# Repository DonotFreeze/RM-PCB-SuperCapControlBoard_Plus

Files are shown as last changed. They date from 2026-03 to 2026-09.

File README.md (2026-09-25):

# 超级电容控制板 Plus

> 桂林理工大学 · 群星战队 · RoboMaster 2025 赛季开源工程

基于 **STM32G431CB** 的单半桥双向同步 Buck-Boost 超级电容控制板，用于RobaMaster机甲大师赛2025赛季超级对抗赛。相较 2024 赛季开源的 Lite 版本，Plus 版本围绕**远端电压补偿**、**下管电流采样**与**硬件保护**三个方面进行了重点改进，并重新设计了充放电环路逻辑。

> **完整的硬件设计说明** → [RM2025 超级电容控制板 Plus「硬件篇」 · DonotFreeze 的知识库](https://donotfreeze.github.io/robomaster/supercap-controller-plus-hardware/)

<p align="center">
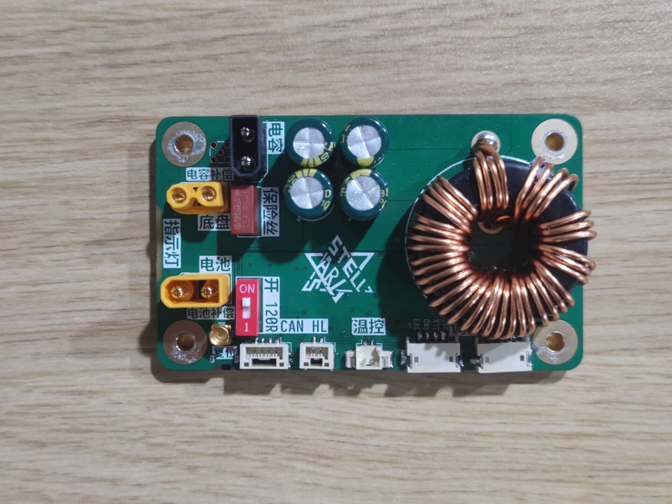
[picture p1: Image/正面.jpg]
超级电容控制板 Plus 正面
  
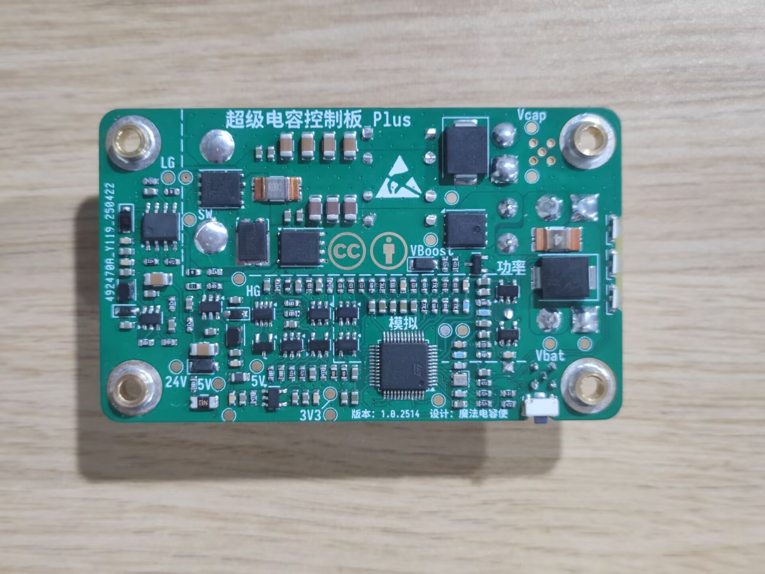
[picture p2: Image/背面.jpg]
超级电容控制板 Plus 背面
  
</p>

## 主要特性

- **远端电压补偿**：通过 MMCX-KWE 接口 + 差分放大器，把电压采样点从板端移到电源管理模块 Chassis 端口，抵消导线线损带来的功率采样误差（24V、0–10A 范围内与裁判系统误差 ≤ ±1W，未补偿时误差约 -5W）。
- **下管续流电流采样**：采用差分放大器进行下管低边采样，搭配 2mΩ 检流电阻，量程 -20A ~ +40A（充电为负、放电为正），有效电流分辨率约 0.1A，取代 Lite 版本的 INA181。节省成本的同时提高可靠性，但是在一定程度上损失了精度。
- **硬件保护**：母线电源端口带有 TVS、并在半桥拓扑支路上有一个5A慢断保险丝，可在一定程度上保证控制板烧毁而不影响母线。辅助电源有自恢复保险丝 + 限流电阻 + 小功率 TVS 的浪涌保护。功率相关引脚 ESD 防护及其熔断检测、PMOS 与 PWM 的硬件时序延迟电路。
- **单电感同步半桥**：PMOS 防倒灌 + 半桥 Buck/Boost，配合硬件/软件时序控制保证 PMOS 先于 PWM 导通、后于 PWM 关断。

## 硬件规格

| 项目 | 参数 |
| --- | --- |
| 主控 | STM32G431CBT6 |
| 拓扑 | 同步 Buck-Boost 半桥（降压充电 / 升压放电） |
| 半桥 MOS | IRFH7440 × 2 |
| 防倒灌 PMOS | AGM60P100A |
| 栅极驱动 | LM5109 |
| 母线电流采样 | 4mΩ + INA139/INA193 兼容 |
| 电流采样 | 2mΩ 分流电阻 + 差分放大器 |
| 温度采样 | 半桥温度NTC + 外接电容组NTC |
| 通信 | CAN |
| 辅助电源 | MP2456 × 2 + RT9193（3.3V） |
| 尺寸 | 45 × 75 × 20 mm（面积与孔位与电容组一致，可直接堆叠） |

## 工程结构

```text
├─ SuperCapControlBoard_Plus.kicad_pro / .kicad_sch / .kicad_pcb   # KiCad 8.0 工程（原理图 + PCB）
├─ POWER.kicad_sch                     # 功率级原理图
├─ BOM/
│  ├─ SuperCapPowerBoard_Plus.csv      # 已附立创商城编号的 BOM
│  └─ ibom.html                        # 交互式 BOM（点击可定位元件）
├─ GERBER/                             # Gerber 生产文件（Plus / PULS 版本）
├─ 模型文件/                           # 3D STEP 模型
├─ Docs/                               # 参考资料（TI《高速低侧电流检测参考设计》）
├─ Image/                              # 文档配图
└─ CHANGELOG.md                        # 版本更新日志
```

## 固件代码

本仓库为**纯硬件工程**，不包含固件源码。固件由以下两个独立仓库提供，与本硬件配套使用：

| 仓库 | 说明 |
| --- | --- |
| [**RM-CODE-SuperCapControlBoard_Plus**](https://github.com/DonotFreeze/RM-CODE-SuperCapControlBoard_Plus) | RM2025 赛季超级电容控制板 Plus 的 **CubeMX 代码初始化工程**，提供 STM32 底层外设的 CubeMX 配置 |
| [**RM-SuperCapCtrlLib**](https://github.com/DonotFreeze/RM-SuperCapCtrlLib) | 参加 RoboMaster 机甲大师赛期间开发的 **C 语言库**，可同时用于超级电容控制板 **Lite 和 Plus**，负责充放电环路控制与对外接口 |

## 物料与打样

- BOM 已附立创商城编号，可直接一键下单；建议一次性采购 10 套用量以获得较优价格（约 90 元/套，2025 年 5 月）。
- 全部芯片若在优信电子采购，成本可再降低约 20 元/套（其中 **MP2456 强烈建议到优信购买**）。
- 磁环电感立创商城无货、未列入 BOM，需自行采购 **106-125 磁环**（四线 1.0mm 并绕 11 匝，初始感量约 22µH），磁芯型号务必一致以保证感量与饱和电流。

---

## 参考文献

- 高速低侧电流检测参考设计 (Rev. C) —— 见 `Docs/《高速低侧电流检测参考设计-TI》.pdf`
- 电源远端电压补偿 / 远端补偿电源电路 —— CSDN 博客

## 特别鸣谢

感谢以下战队在 Lite 版本中的使用反馈（排名不分先后，想到谁就写谁）：

- 江南大学霞客湾校区 - SHARK 战队
- 北京理工大学珠海学院 - 毅恒战队
- 厦门大学嘉庚学院 - TCR 战队
- 宁波诺丁汉大学 - AIM 战队
- 浙江理工大学 - 钱塘蛟战队

## 许可证

本作品采用 [CC-BY-4.0](https://creativecommons.org/licenses/by/4.0/legalcode) 许可协议进行授权，欢迎转载，但请务必保留作者署名。

## 相关链接

- [RM2025 超级电容控制板 Plus「硬件篇」](https://donotfreeze.github.io/robomaster/supercap-controller-plus-hardware/)（本工程的设计说明）
- [固件代码 · RM-CODE-SuperCapControlBoard_Plus](https://github.com/DonotFreeze/RM-CODE-SuperCapControlBoard_Plus)（CubeMX 代码初始化工程）
- [固件代码 · RM-SuperCapCtrlLib](https://github.com/DonotFreeze/RM-SuperCapCtrlLib)（Lite / Plus 通用的 C 语言库）
- [RM2024 超级电容控制板 Lite「硬件篇」](https://donotfreeze.github.io/robomaster/supercap-controller-lite-hardware/)
- [RM2025 超级电容模组 Plus「使用手册」](https://donotfreeze.github.io/robomaster/supercap-module-plus-user-manual/)
- [RM24-25 超级电容控制板 Lite & Plus「CubeMX 篇」](https://donotfreeze.github.io/robomaster/supercap-controller-cubemx/)
- [RM24-25 超级电容模组 Lite & Plus「答疑篇」](https://donotfreeze.github.io/robomaster/supercap-module-faq/)
- [DonotFreeze 的知识库](https://donotfreeze.github.io/)

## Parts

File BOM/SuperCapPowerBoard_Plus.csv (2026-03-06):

Reference | Value | Footprint | Qty | 型号 | 立创编号
C1,C3,C8,C9,C10,C11,C13,C16,C18,C19,C20,C21,C27,C29,C30,C31,C32,C33,C34,C38,C39,C41,C42,C43,C47,C49,C53,C57,C59,C60 | 100nF | 0_Capacitor_SMD:C_0603_1608Metric | 30 | 0603B104K500NT | C30926
C2,C12,C17,C22 | 4.7uF | 0_Capacitor_SMD:C_0603_1608Metric | 4 | 0603X475M100NT | C2857987
C4,C5,C6 | 47nF | 0_Capacitor_SMD:C_0603_1608Metric | 3 | 0603B473K500NT | C285123
C7 | 1nF | 0_Capacitor_SMD:C_0603_1608Metric | 1 | 0603B102K500NT | C44369
C14,C15 | 12pF | 0_Capacitor_SMD:C_0603_1608Metric | 2 | 0603CG120J500NT | C1642
C23,C44,C45,C46,C56,C58 | 10uF | 0_Capacitor_SMD:C_0603_1608Metric | 6 | 0603X106K160NT | C70225
C24,C25,C35,C36,C37,C51,C52,C54,C55 | 10uF | Capacitor_SMD:C_1206_3216Metric | 9 | 1206X106K500NT | C116702
C26,C28,C48,C50 | 100uF | Capacitor_THT:CP_Radial_D8.0mm_P3.50mm | 4 | CD2881071HM0812VFL | C7493835
C40 | 22nF | 0_Capacitor_SMD:C_0603_1608Metric | 1 | 0603B223K500NT | C77571
D1 | XL-3210UGC | 0_LED_SMD:LED_1204_3210 | 1 | XL-3210UGC | C965877
D2 | XL-3210UBC | 0_LED_SMD:LED_1204_3210 | 1 | XL-3210UBC | C965879
D3 | PESD24VL2B | Package_TO_SOT_SMD:SOT-23 | 1 | PESD24VL2B | C28310452
D4 | XL-3210SURC | 0_LED_SMD:LED_1204_3210 | 1 | XL-3210SURC | C965874
D5 | SMF26A | Diode_SMD:D_SMF | 1 | SMF26A | C41376090
D6 | SMF12A | Diode_SMD:D_SMF | 1 | SMF12A | C19077506
D7,D8 | 1N5819WS | Diode_SMD:D_SOD-323_HandSoldering | 2 | 1N5819WS | C2927280
D9 | SB1045L | Package_TO_SOT_SMD:TO-277A | 1 | SB1045L | C5277965
D10,D11 | SMCJ28A | Diode_SMD:D_SMC | 2 | SMCJ28A | C42371538
D12 | 1N5819W | Diode_SMD:D_SOD-123F | 1 | 1N5819W | C963381
F1 | 1206L010/60NR | Fuse:Fuse_1206_3216Metric | 1 | 1206L010/60NR | C7542927
F2 | 2010T5A250V | 0_Fuse:Fuse_Littelfuse_395Series | 1 | 2010T5A250V | C354906
J1,J2 | MMCX-KWE | 0_Connector_RF:MMCX_KWE_TH_Horizontal | 2 | MMCX-KWE | C5137199
J3 | MX1.25-2PIN | Connector_Molex:Molex_PicoBlade_53398-0271_1x02-1MP_P1.25mm_Vertical | 1 | ZX-MX1.25-2PLT | C7430473
J4 | GH1.25-2PIN | Connector_JST:JST_GH_BM02B-GHS-TBT_1x02-1MP_P1.25mm_Vertical | 1 | ZX-BX-GH1.25-LT2 | C7429506
J5 | GH1.25-4PIN | Connector_JST:JST_GH_BM04B-GHS-TBT_1x04-1MP_P1.25mm_Vertical | 1 | ZX-BX-GH1.25-LT4 | C7429508
J6,J7 | ZH1.5_4PIN | 0_Connector_JST:JST_ZH_1x04_-1MP_P1.5mm_MIX_MX_1x04-1MP_P1.25_Horizontal | 2 | ZX-ZH1.5-4PWT | C19272407
L1 | 330R@100Mhz | Inductor_SMD:L_0805_2012Metric | 1 | BLM21PG331SN1D | C74764
L2,L3 | APSWPA252012S220MTF | Inductor_SMD:L_Sunlord_SWPA252012S | 2 | APSWPA252012S220MTF | C42380099
Q1 | DTC143ZCA | Package_TO_SOT_SMD:SOT-23 | 1 | DTC143ZCA | C194251
Q2 | AGM60P100A | Package_DFN_QFN:AO_DFN-8-1EP_5.55x5.2mm_P1.27mm_EP4.12x4.6mm | 1 | AGM60P100A | C5373096
Q3,Q4 | IRFH7440 | Package_TO_SOT_SMD:TDSON-8-1 | 2 | IRFH7440 | C67862
R1,R2,R3,R4,R5,R6,R30,R35 | 10K | 0_Resustor_SMD:R_0603_1608Metric | 8 | RS-03K1002FT | C115324
R7,R8,R9,R10 | 1M | 0_Resustor_SMD:R_0603_1608Metric | 4 | RS-03K1004FT | C136593
R11,R17 | 200K | 0_Resustor_SMD:R_0603_1608Metric | 2 | RS-03K2003FT | C95331
R12 | 20K | 0_Resustor_SMD:R_0603_1608Metric | 1 | RS-03K2002FT | C136589
R13,R14,R15,R16 | 62K | 0_Resustor_SMD:R_0603_1608Metric | 4 | RS-03K6202FT | C95332
R18,R19,R20,R21 | 330R | 0_Resustor_SMD:R_0603_1608Metric | 4 | RS-03K3300FT | C125768
R22,R25,R33,R34,R37 | 47R | 0_Resustor_SMD:R_0603_1608Metric | 5 | RS-03K47R0FT | C140087
R23,R24,R27,R32,R38,R39,R52,R53,R54,R55 | 4K7 | 0_Resustor_SMD:R_0603_1608Metric | 10 | RS-03K4701FT | C116693
R26,R29,R31,R40,R41,R42,R47,R48 | 47K | 0_Resustor_SMD:R_0603_1608Metric | 8 | RS-03K4702FT | C136590
R28 | 120R | 0_Resustor_SMD:R_0603_1608Metric | 1 | RS-03K1200FT | C310266
R36,R43,R44 | 3K3 | 0_Resustor_SMD:R_0603_1608Metric | 3 | RS-03K3301FT | C118393
R45,R46 | 0R | 0_Resustor_SMD:R_0603_1608Metric | 2 | RS-03000JT | C115304
R49 | 39K | 0_Resustor_SMD:R_0603_1608Metric | 1 | RS-03K3902FT | C304745
R50 | 18K | 0_Resustor_SMD:R_0603_1608Metric | 1 | RS-03K1802FT | C140113
R51 | R002 | 0_Resustor_SMD:R_Shunt_2512_6332Metric | 1 | HoSS2512-3W-2mR-1% | C5336185
R56 | R004 | 0_Resustor_SMD:R_Shunt_2512_6332Metric | 1 | HoSS2512-3W-4mR-1% | C5336187
SW1 | TS-1086EV-16 | 0_Button_Switch_SMD:SW_Push_1P1T-MP_NO_TS-1086EV-AR03526 | 1 | TS-1086EV-16 | C455277
SW2 | DIP-1PIN-TH | Button_Switch_THT:SW_DIP_SPSTx01_Slide_9.78x4.72mm_W7.62mm_P2.54mm | 1 | BX-DS2.54-1PZC | C18078246
TH1 | B3950-100K | 0_Resustor_SMD:R_0603_1608Metric | 1 | SDNT1608X104F3950FTF | C919169
U1,U5,U6 | USBLC6-2SC6 | Package_TO_SOT_SMD:SOT-23-6 | 3 | USBLC6-2SC6 | C21713975
U2 | INA193 | Package_TO_SOT_SMD:SOT-23-5 | 1 | INA193AIDBVR | C19548
U3 | TLV9061 | Package_TO_SOT_SMD:SOT-23-5 | 1 | TLV9061IDBVR | C398358
U4 | TCAN1044 | Package_TO_SOT_SMD:SOT-23-8 | 1 | TCAN1044ADDFRQ1 | C3236212
U7 | STM32G431CxTx | Package_QFP:LQFP-48_7x7mm_P0.5mm | 1 | STM32G431CBT6 | C529355
U8,U9 | MP2456 | Package_TO_SOT_SMD:SOT-23-6 | 2 | MP2456GJ-Z | C88045
U10 | RT9193 | Package_TO_SOT_SMD:SOT-23-5 | 1 | RT9193-33GB | C15651
U11 | 74LVC1G32 | Package_TO_SOT_SMD:SOT-23-5 | 1 | SN74LVC1G32DBVR | C19829663
U12 | 74LVC1G08 | Package_TO_SOT_SMD:SOT-23-5 | 1 | SN74LVC1G08DBVR | C19829660
U13 | LM5109 | Package_SO:SOIC-8_3.9x4.9mm_P1.27mm | 1 | LM5109BMAX/NOPB | C116862
XT1,XT2 | XT30U-M | 0_Connector_AMASS:AMASS_XT30U-M_1x02_P5.0mm_Vertical | 2 | XT30U-M | C99101
XT3 | XT30U-F | 0_Connector_AMASS:AMASS_XT30U-F_1x02_P5.0mm_Vertical | 1 | XT30U-F | C99102
Y1 | 25M | Crystal:Crystal_SMD_2016-4Pin_2.0x1.6mm | 1 | XL7EL89CKI-111YLC-25M | C19711739

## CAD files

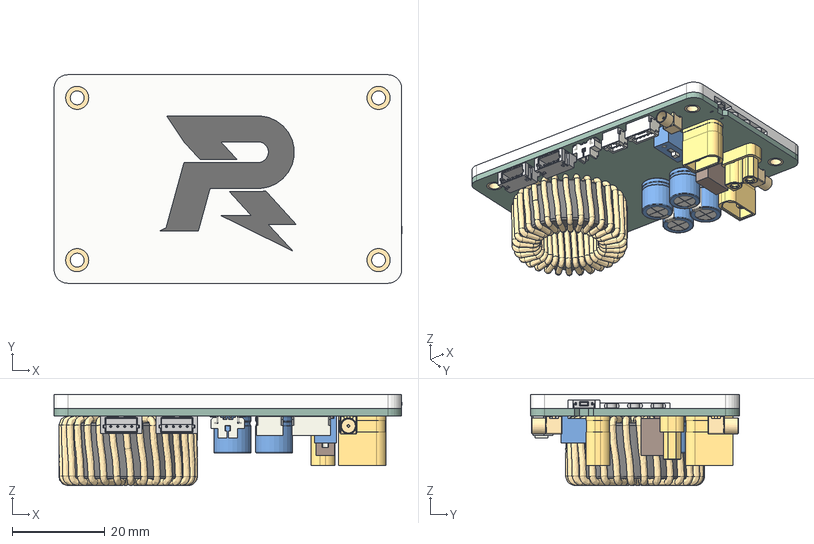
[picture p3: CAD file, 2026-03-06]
模型文件/SuperCapControlBoard_Plus_Full.step
75.1 x 45.0 x 19.7 mm
C_0603_1608Metric_1 x 47
R_0603_1608Metric_1 x 55
Fuse_1206_3216Metric_1
SW1~SW-SMD_TS-1086EV-16~SW-SMD_TS-1086EV-16~iBmK
C_1206_3216Metric_1 x 9
D_SMC_1 x 2
SOT_23_6 x 5
TDSON_8_1 x 2
U2~LED-SMD_3P-L3.2-W1.5-RD_GREEN~LED-SMD_3P-L3.2-W1.5-RD_GREEN~iBmK x 3
CQ assembly
TO_277A_sp
SOT_23_5 x 5
R_2512_6332Metric_1 x 2
SOT_23 x 2
SOIC_8_39x49mm_P127mm
SOT_23_8
D_SOD_123F
D_SOD_323 x 2
D_SMF_1 x 2
LQFP_48_7x7mm_P05mm
CQ assembly_1 x 2
L_0805_2012Metric_1
CP_Radial_D80mm_P350mm x 4
JST_BM02B_GHS_TBT
106125 v2
F1~FUSE-TH_L8.5-W4.0-P5.08-D0.6~FUSE-TH_L8.5-W4.0-H8.5-P5.08~GtJy
U1~CONN-TH_XT30U-F~CONN-TH_XT30U-F~Cvbw
MMCX v2 x 2
3D_PCB1_2025-04-07 (1) v6 x 2
CN1~CONN-TH_XT30U-M~CONN-TH_XT30U-M~Cvbw x 2
Molex_53398_0271
SW_DIP_SPSTx01_Slide_978x472mm_W762mm_P254mm
JST_BM04B_GHS_TBT
SuperCapControlBoard_Plus_PCB
贴片铜柱
底板

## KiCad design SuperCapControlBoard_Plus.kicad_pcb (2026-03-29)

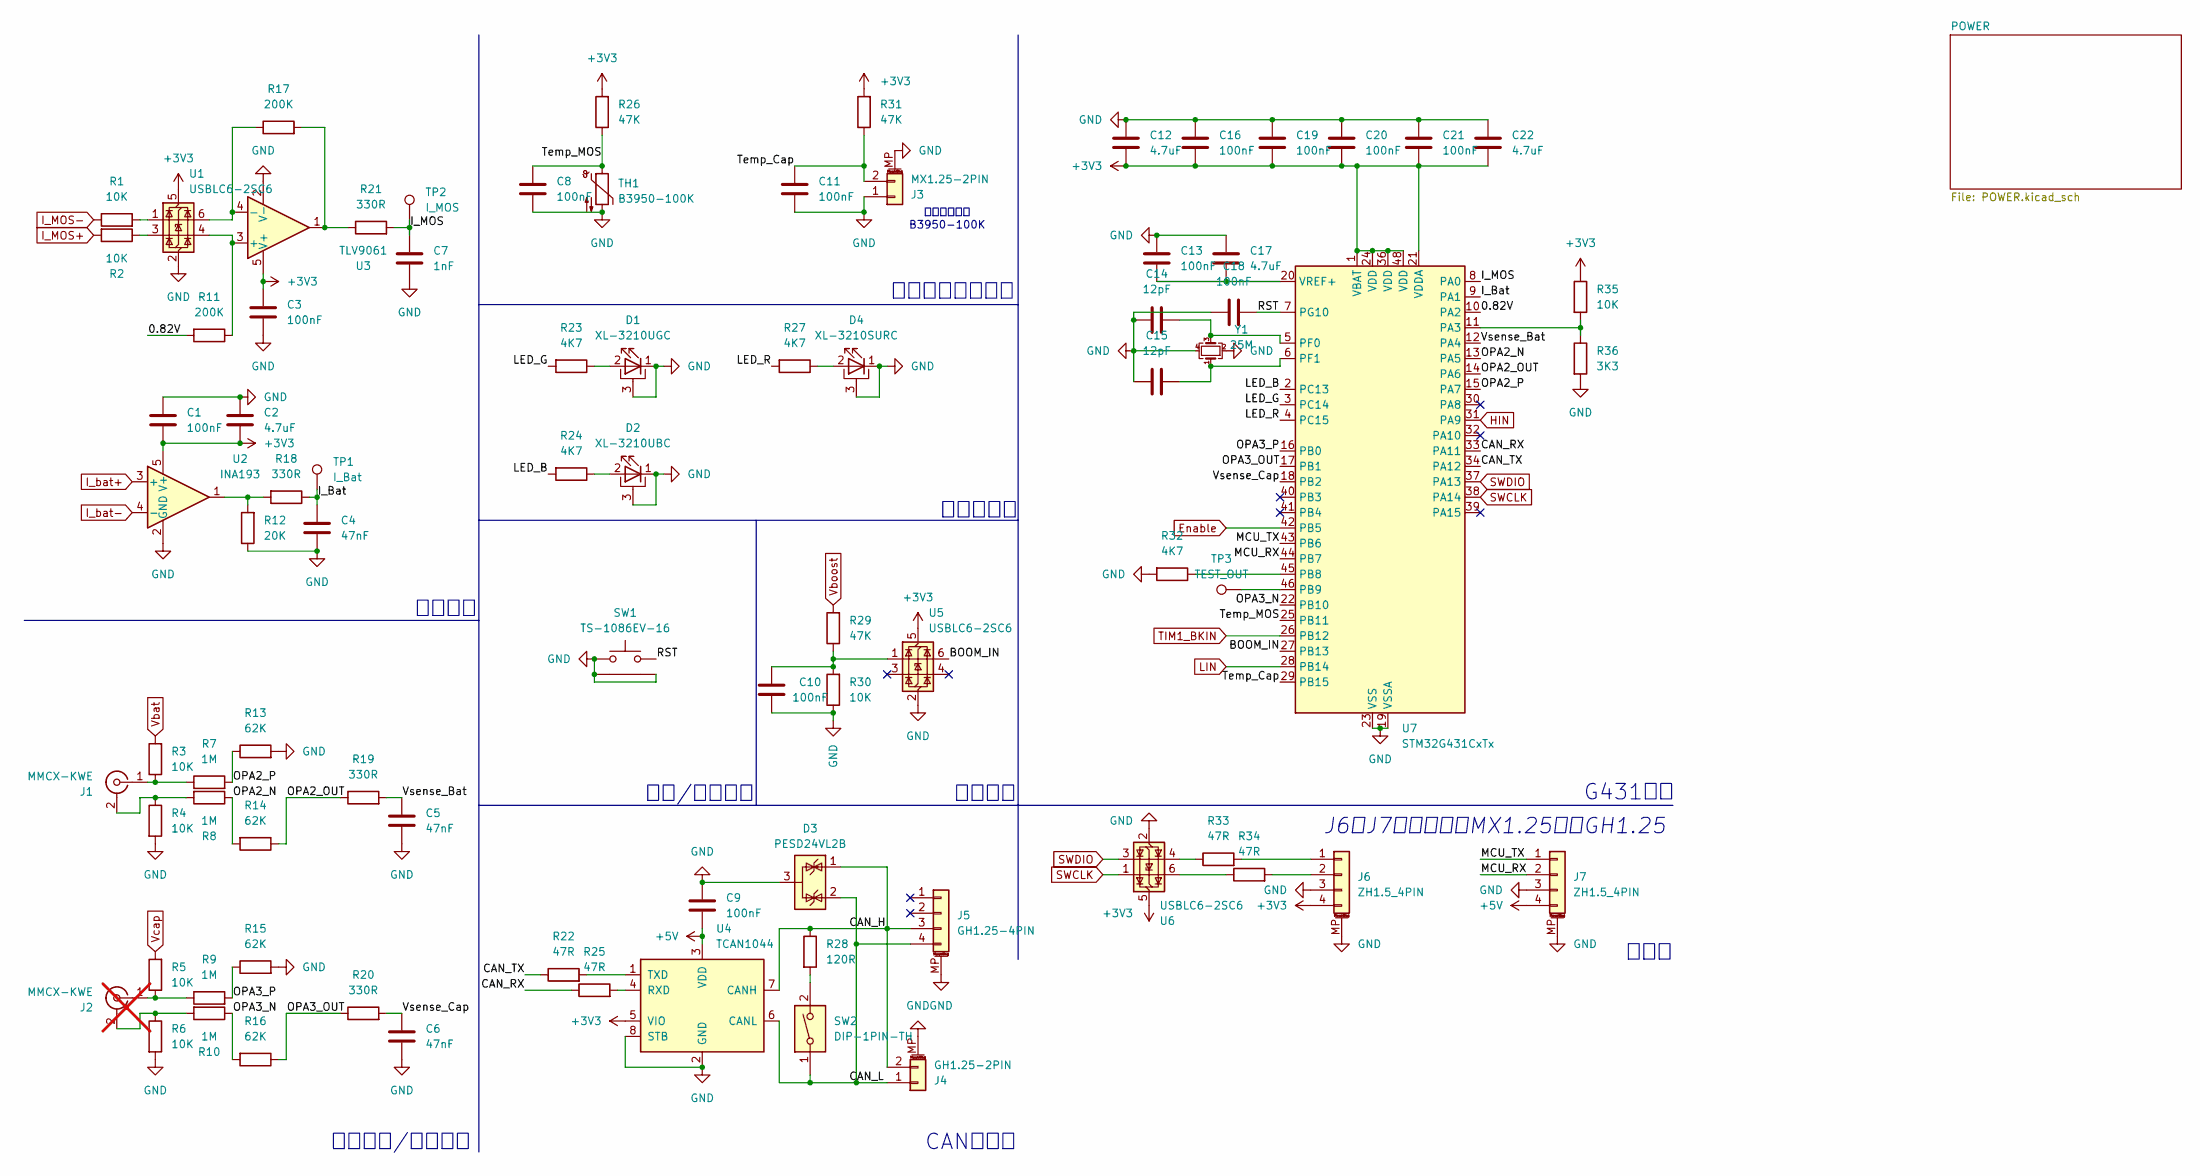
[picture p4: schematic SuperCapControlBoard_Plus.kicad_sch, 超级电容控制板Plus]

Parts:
C1, C3, C8, C9, C10, C11, C13, C16, C18, C19, C20, C21: 100nF; C_0603_1608Metric
C2, C12, C17, C22: 4.7uF; C_0603_1608Metric
C4, C5, C6: 47nF; C_0603_1608Metric
C7: 1nF; C_0603_1608Metric
C14, C15: 12pF; C_0603_1608Metric
D1: XL-3210UGC; LED_1204_3210
D2: XL-3210UBC; LED_1204_3210
D3: PESD24VL2B; SOT-23
D4: XL-3210SURC; LED_1204_3210
J1: MMCX-KWE; MMCX_KWE_TH_Horizontal
J2: MMCX-KWE; MMCX_KWE_TH_Horizontal; not fitted
J3: MX1.25-2PIN; Molex_PicoBlade_53398-0271_1x02-1MP_P1.25mm_Vertical
J4: GH1.25-2PIN; JST_GH_BM02B-GHS-TBT_1x02-1MP_P1.25mm_Vertical
J5: GH1.25-4PIN; JST_GH_BM04B-GHS-TBT_1x04-1MP_P1.25mm_Vertical
J6, J7: ZH1.5_4PIN; JST_ZH_1x04_-1MP_P1.5mm_MIX_MX_1x04-1MP_P1.25_Horizontal
R1, R2, R3, R4, R5, R6, R30, R35: 10K; R_0603_1608Metric
R7, R8, R9, R10: 1M; R_0603_1608Metric
R11, R17: 200K; R_0603_1608Metric
R12: 20K; R_0603_1608Metric
R13, R14, R15, R16: 62K; R_0603_1608Metric
R18, R19, R20, R21: 330R; R_0603_1608Metric
R22, R25, R33, R34: 47R; R_0603_1608Metric
R23, R24, R27, R32: 4K7; R_0603_1608Metric
R26, R29, R31: 47K; R_0603_1608Metric
R28: 120R; R_0603_1608Metric
R36: 3K3; R_0603_1608Metric
SW1: TS-1086EV-16; SW_Push_1P1T-MP_NO_TS-1086EV-AR03526
SW2: DIP-1PIN-TH; SW_DIP_SPSTx01_Slide_9.78x4.72mm_W7.62mm_P2.54mm
TH1: B3950-100K; R_0603_1608Metric
TP1: I_Bat; TestPoint_Pad_D1.5mm
TP2: I_MOS; TestPoint_Pad_D1.5mm
TP3: TEST_OUT; TestPoint_Pad_D1.5mm
U1, U5, U6: USBLC6-2SC6; SOT-23-6
U2: INA193; SOT-23-5
U3: TLV9061; SOT-23-5
U4: TCAN1044; SOT-23-8
U7: STM32G431CxTx; LQFP-48_7x7mm_P0.5mm
Y1: 25M; Crystal_SMD_2016-4Pin_2.0x1.6mm

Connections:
+3V3: C1.1, C2.1, C3.2, C12.2, C16.2, C19.2, C20.2, C21.2, C22.2, J6.4, R26.2, R31.2, R35.1, U1.5 (VBUS), U2.5 (V+), U3.5 (V+), U4.5 (VIO), U5.5 (VBUS), U6.5 (VBUS), U7.1 (VBAT), U7.21 (VDDA), U7.24 (VDD), U7.36 (VDD), U7.48 (VDD); also elsewhere on the board
+5V: C9.2, J7.4, U4.3 (VDD); also elsewhere on the board
/0.82V: R11.2, U7.10 (PA2)
/BOOM_IN: U5.6 (I/O1), U7.27 (PB13)
/CAN_H: D3.1 (K), J4.2, J5.3, R28.1, U4.7 (CANH)
/CAN_L: D3.2 (K), J4.1, J5.4, SW2.1, U4.6 (CANL)
/CAN_RX: R25.1, U7.33 (PA11)
/CAN_TX: R22.1, U7.34 (PA12)
/I_Bat: C4.2, R18.1, TP1.1, U7.9 (PA1)
/I_MOS: C7.2, R21.2, TP2.1, U7.8 (PA0)
/LED_B: R24.2, U7.2 (PC13)
/LED_G: R23.2, U7.3 (PC14)
/LED_R: R27.2, U7.4 (PC15)
/MCU_RX: J7.2, U7.44 (PB7)
/MCU_TX: J7.1, U7.43 (PB6)
/OPA2_N: R8.1, R14.2, U7.13 (PA5)
/OPA2_OUT: R14.1, R19.1, U7.14 (PA6)
/OPA2_P: R7.2, R13.1, U7.15 (PA7)
/OPA3_N: R10.1, R16.2, U7.22 (PB10)
/OPA3_OUT: R16.1, R20.1, U7.17 (PB1)
/OPA3_P: R9.2, R15.1, U7.16 (PB0)
/RST: C18.2, SW1.1, U7.7 (PG10)
/Temp_Cap: C11.1, J3.2, R31.1, U7.29 (PB15)
/Temp_MOS: C8.1, R26.1, TH1.1, U7.25 (PB11)
/Vsense_Bat: C5.2, R19.2, U7.12 (PA4)
/Vsense_Cap: C6.2, R20.2, U7.18 (PB2)
Enable: U7.42 (PB5); also elsewhere on the board
GND: C1.2, C2.2, C3.1, C4.1, C5.1, C6.1, C7.1, C8.2, C9.1, C10.2, C11.2, C12.1, C13.1, C14.2, C15.2, C16.1, C17.1, C18.1, C19.1, C20.1, C21.1, C22.1, D1.1 (K), D1.3 (PAD), D2.1 (K), D2.3 (PAD), D3.3 (A), D4.1 (K), D4.3 (PAD), J3.1, J3.MP (MountPin), J4.MP (MountPin), J5.MP (MountPin), J6.3, J6.MP (MountPin), J7.3, J7.MP (MountPin), R4.2, R6.2, R12.1, R13.2, R15.2, R30.1, R32.2, R36.2, SW1.2, SW1.MP, TH1.2, U1.2 (GND), U2.2 (GND), U3.2 (V-), U4.2 (GND), U4.8 (STB), U5.2 (GND), U6.2 (GND), U7.19 (VSSA), U7.23 (VSS), U7.35 (VSS), U7.47 (VSS), Y1.2, Y1.4; also elsewhere on the board
HIN: U7.31 (PA9); also elsewhere on the board
I_MOS+: R2.2; also elsewhere on the board
I_MOS-: R1.1; also elsewhere on the board
I_bat+: U2.3 (+); also elsewhere on the board
I_bat-: U2.4 (-); also elsewhere on the board
LIN: U7.28 (PB14); also elsewhere on the board
unnamed: C10.1, R29.1, R30.2, U5.1 (I/O1)
unnamed: D1.2 (A), R23.1
unnamed: D2.2 (A), R24.1
unnamed: D4.2 (A), R27.1
unnamed: J1.2 (Ext), R4.1, R8.2
unnamed: J1.1 (In), R3.1, R7.1
unnamed: J2.2 (Ext), R6.1, R10.2
unnamed: J2.1 (In), R5.1, R9.1
unnamed: J6.1, R33.2
unnamed: J6.2, R34.2
unnamed: R1.2, U1.1 (I/O1)
unnamed: R2.1, U1.3 (I/O2)
unnamed: R12.2, R18.2, U2.1
unnamed: R17.2, R21.1, U3.1
unnamed: R28.2, SW2.2
unnamed: R33.1, U6.4 (I/O2)
unnamed: R34.1, U6.6 (I/O1)
unnamed: R11.1, U1.4 (I/O2), U3.3 (+)
unnamed: R17.1, U1.6 (I/O1), U3.4 (-)
unnamed: R25.2, U4.4 (RXD)
unnamed: R22.2, U4.1 (TXD)
unnamed: R35.2, R36.1, U7.11 (PA3)
unnamed: R32.1, U7.45 (PB8)
unnamed: TP3.1, U7.46 (PB9)
unnamed: C14.1, U7.5 (PF0), Y1.3
unnamed: C15.1, U7.6 (PF1), Y1.1
unnamed: C13.2, C17.2, U7.20 (VREF+)
SWCLK: U6.1 (I/O1), U7.38 (PA14)
SWDIO: U6.3 (I/O2), U7.37 (PA13)
TIM1_BKIN: U7.26 (PB12); also elsewhere on the board
Vbat: R3.2; also elsewhere on the board
Vboost: R29.2; also elsewhere on the board
Vcap: R5.2; also elsewhere on the board

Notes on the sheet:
CAN收发器
J6和J7的焊盘兼容MX1.25或者GH1.25
爆炸检测
电压检测/远端补偿
G431主控
调试口
外接热敏电阻 B3950-100K
电流检测
复位/复用按键
状态指示灯
热敏电阻温度检测

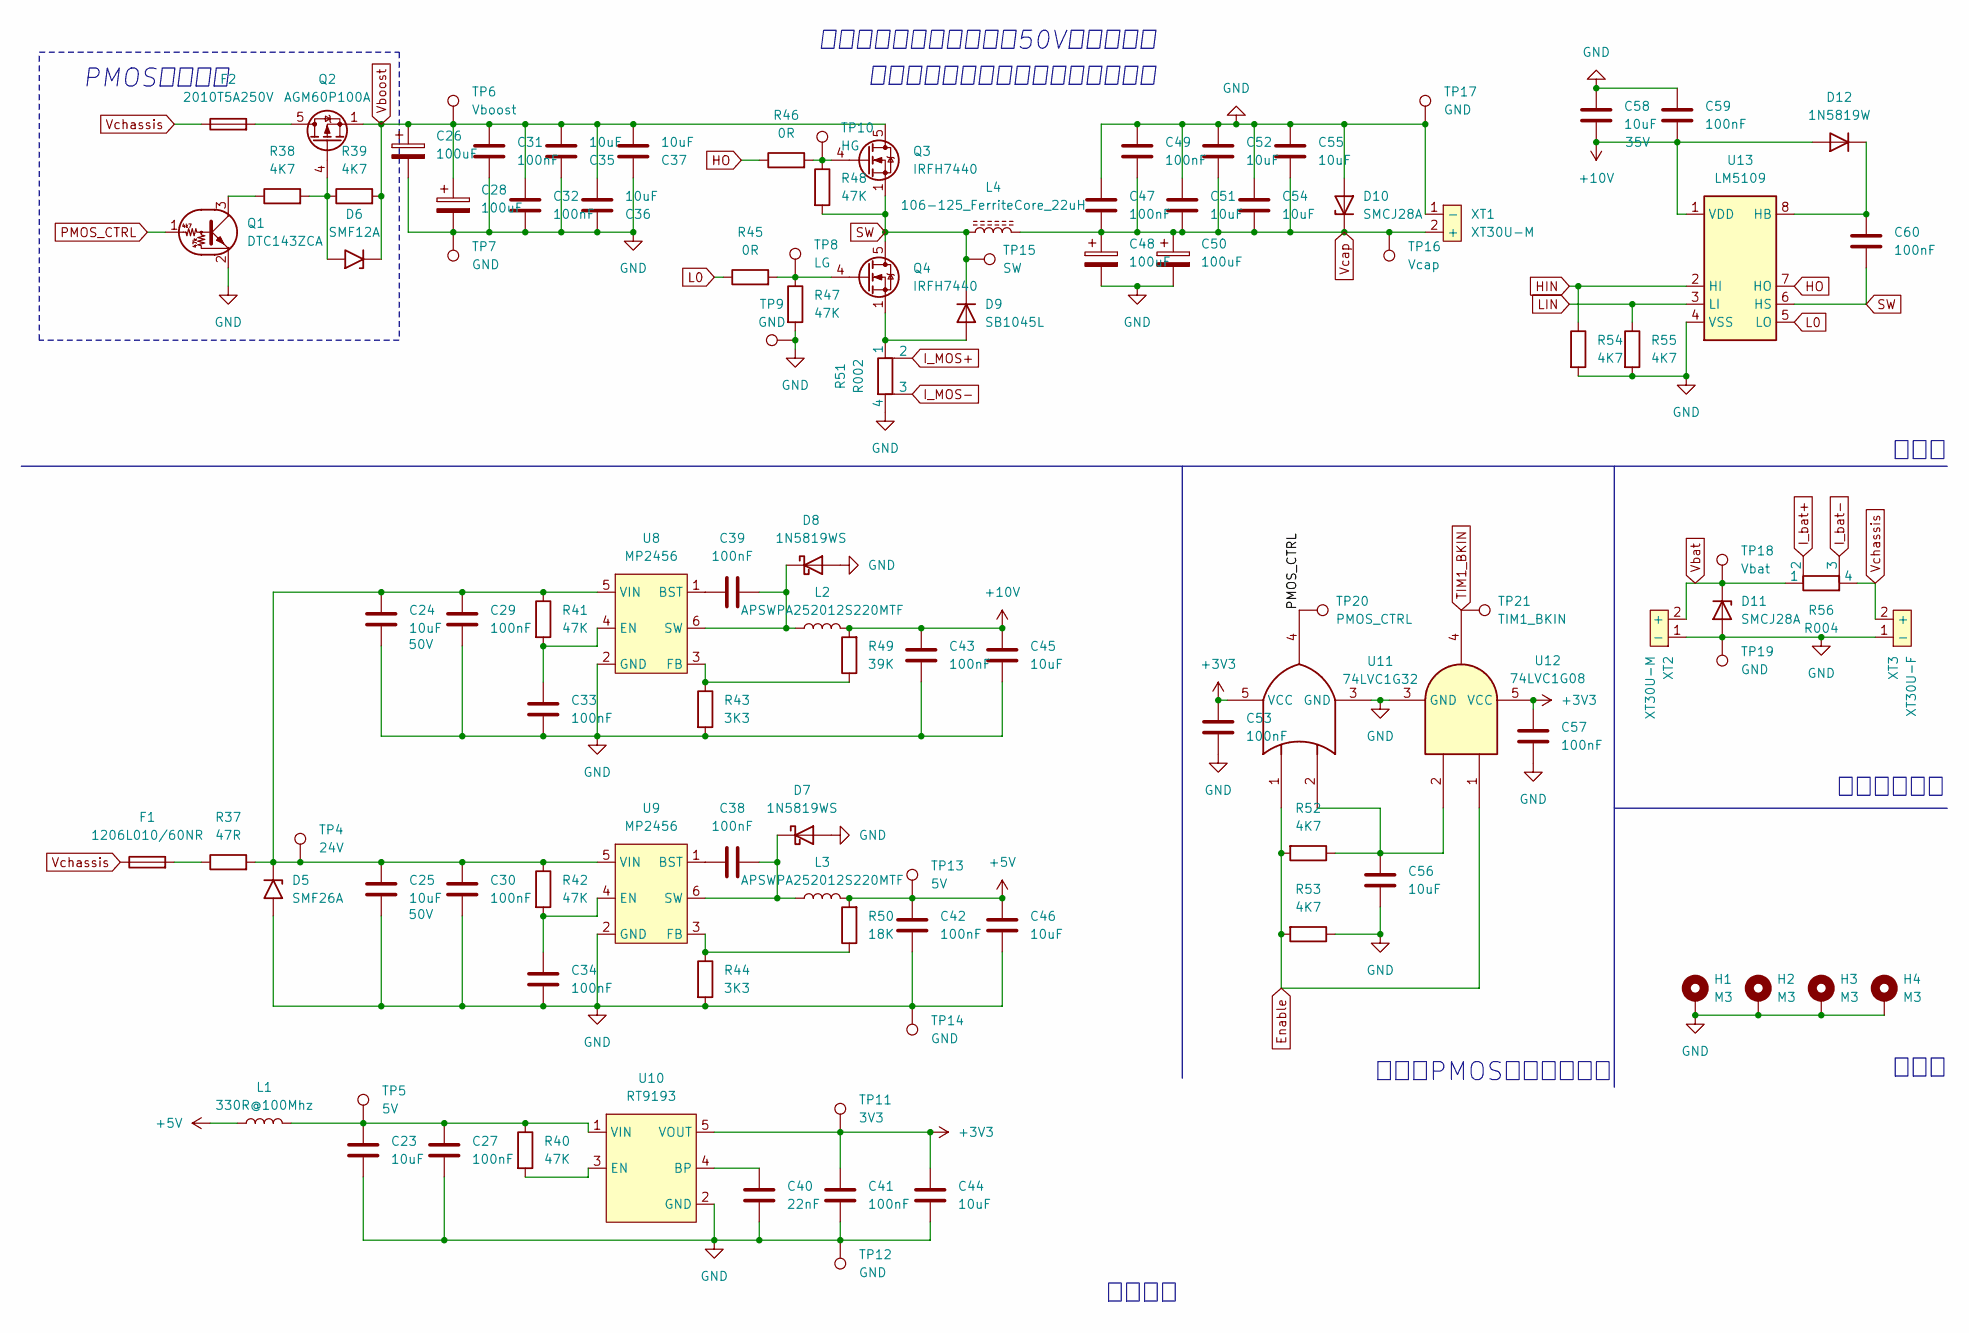
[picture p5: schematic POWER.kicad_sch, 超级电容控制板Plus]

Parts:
C23, C44, C45, C46, C56, C58: 10uF; C_0603_1608Metric
C24, C25, C35, C36, C37, C51, C52, C54, C55: 10uF; C_1206_3216Metric
C26, C28, C48, C50: 100uF; CP_Radial_D8.0mm_P3.50mm
C27, C29, C30, C31, C32, C33, C34, C38, C39, C41, C42, C43, C47, C49, C53, C57, C59, C60: 100nF; C_0603_1608Metric
C40: 22nF; C_0603_1608Metric
D5: SMF26A; D_SMF
D6: SMF12A; D_SMF
D7, D8: 1N5819WS; D_SOD-323_HandSoldering
D9: SB1045L; TO-277A
D10, D11: SMCJ28A; D_SMC
D12: 1N5819W; D_SOD-123F
F1: 1206L010/60NR; Fuse_1206_3216Metric
F2: 2010T5A250V; Fuse_Littelfuse_395Series
H1, H2, H3, H4: M3; MountingHole_4mm_Pad
L1: 330R@100Mhz; L_0805_2012Metric
L2, L3: APSWPA252012S220MTF; L_Sunlord_SWPA252012S
L4: 106-125_FerriteCore_22uH; L_106125
Q1: DTC143ZCA; SOT-23
Q2: AGM60P100A; AO_DFN-8-1EP_5.55x5.2mm_P1.27mm_EP4.12x4.6mm
Q3, Q4: IRFH7440; TDSON-8-1
R37: 47R; R_0603_1608Metric
R38, R39, R52, R53, R54, R55: 4K7; R_0603_1608Metric
R40, R41, R42, R47, R48: 47K; R_0603_1608Metric
R43, R44: 3K3; R_0603_1608Metric
R45, R46: 0R; R_0603_1608Metric
R49: 39K; R_0603_1608Metric
R50: 18K; R_0603_1608Metric
R51: R002; R_Shunt_2512_6332Metric
R56: R004; R_Shunt_2512_6332Metric
TP4: 24V; TestPoint_Pad_D1.5mm
TP5, TP13: 5V; TestPoint_Pad_D1.5mm
TP6: Vboost; TestPoint_Pad_D1.5mm
TP7, TP9, TP12, TP14, TP17, TP19: GND; TestPoint_Pad_D1.5mm
TP8: LG; TestPoint_Pad_D1.5mm
TP10: HG; TestPoint_Pad_D1.5mm
TP11: 3V3; TestPoint_Pad_D1.5mm
TP15: SW; TestPoint_Pad_D1.5mm
TP16: Vcap; TestPoint_Pad_D1.5mm
TP18: Vbat; TestPoint_Pad_D1.5mm
TP20: PMOS_CTRL; TestPoint_Pad_D1.5mm
TP21: TIM1_BKIN; TestPoint_Pad_D1.5mm
U8, U9: MP2456; SOT-23-6
U10: RT9193; SOT-23-5
U11: 74LVC1G32; SOT-23-5
U12: 74LVC1G08; SOT-23-5
U13: LM5109; SOIC-8_3.9x4.9mm_P1.27mm
XT1, XT2: XT30U-M; AMASS_XT30U-M_1x02_P5.0mm_Vertical
XT3: XT30U-F; AMASS_XT30U-F_1x02_P5.0mm_Vertical

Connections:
+3V3: C41.1, C44.1, C53.1, C57.1, TP11.1, U10.5 (VOUT), U11.5 (VCC), U12.5 (VCC); also elsewhere on the board
+5V: C42.1, C46.1, L1.1, L3.2, R50.2, TP13.1; also elsewhere on the board
+10V: C43.1, C45.1, C58.2, C59.1, D12.2 (A), L2.2, R49.2, U13.1 (VDD)
Enable: R52.2, R53.2, U11.1, U12.1; also elsewhere on the board
GND: C23.2, C24.2, C25.2, C26.2, C27.2, C28.2, C29.2, C30.2, C31.1, C32.1, C33.1, C34.1, C35.1, C36.1, C37.1, C40.2, C41.2, C42.2, C43.2, C44.2, C45.2, C46.2, C47.2, C48.2, C49.2, C50.2, C51.1, C52.1, C53.2, C54.1, C55.1, C56.2, C57.2, C58.1, C59.2, D5.2 (A2), D7.2 (A), D8.2 (A), D10.2 (A), D11.2 (A), H1.1, H2.1, H3.1, H4.1, Q1.2 (E), R43.2, R44.2, R47.2, R51.4, R53.1, R54.2, R55.2, TP7.1, TP9.1, TP12.1, TP14.1, TP17.1, TP19.1, U8.2 (GND), U9.2 (GND), U10.2 (GND), U11.3 (GND), U12.3 (GND), U13.4 (VSS), XT1.1 (-), XT2.1 (-), XT3.1 (-); also elsewhere on the board
HIN: R54.1, U13.2 (HI); also elsewhere on the board
HO: R46.1, U13.7 (HO)
I_MOS+: R51.2; also elsewhere on the board
I_MOS-: R51.3; also elsewhere on the board
I_bat+: R56.2; also elsewhere on the board
I_bat-: R56.3; also elsewhere on the board
L0: R45.1, U13.5 (LO)
LIN: R55.1, U13.3 (LI); also elsewhere on the board
unnamed: C56.1, R52.1, U11.2, U12.2
unnamed: C24.1, C25.1, C29.1, C30.1, D5.1 (A1), R37.2, R41.1, R42.1, TP4.1, U8.5 (VIN), U9.5 (VIN)
unnamed: D6.2 (A2), Q2.4 (G), R38.2, R39.1
unnamed: C38.2, D7.1 (K), L3.1, U9.6 (SW)
unnamed: C39.2, D8.1 (K), L2.1, U8.6 (SW)
unnamed: D9.1 (A), D9.2 (A), Q4.1 (S), Q4.2 (S), Q4.3 (S), R51.1
unnamed: C60.1, D12.1 (K), U13.8 (HB)
unnamed: F1.2, R37.1
unnamed: Q1.3 (C), R38.1
unnamed: F2.2, Q2.5 (D)
unnamed: Q3.4 (G), R46.2, R48.1, TP10.1
unnamed: Q4.4 (G), R45.2, R47.1, TP8.1
unnamed: C39.1, U8.1 (BST)
unnamed: C33.2, R41.2, U8.4 (EN)
unnamed: R43.1, R49.1, U8.3 (FB)
unnamed: C38.1, U9.1 (BST)
unnamed: C34.2, R42.2, U9.4 (EN)
unnamed: R44.1, R50.1, U9.3 (FB)
unnamed: C40.1, U10.4 (BP)
unnamed: R40.2, U10.3 (EN)
unnamed: C23.1, C27.1, L1.2, R40.1, TP5.1, U10.1 (VIN)
PMOS_CTRL: Q1.1 (B), TP20.1, U11.4
SW: C60.2, D9.3 (K), L4.2, Q3.1 (S), Q3.2 (S), Q3.3 (S), Q4.5 (D), R48.2, TP15.1, U13.6 (HS)
TIM1_BKIN: TP21.1, U12.4; also elsewhere on the board
Vbat: D11.1 (K), R56.1, TP18.1, XT2.2 (+); also elsewhere on the board
Vboost: C26.1, C28.1, C31.2, C32.2, C35.2, C36.2, C37.2, D6.1 (A1), Q2.1 (S), Q2.2 (S), Q2.3 (S), Q3.5 (D), R39.2, TP6.1; also elsewhere on the board
Vcap: C47.1, C48.1, C49.1, C50.1, C51.2, C52.2, C54.2, C55.2, D10.1 (K), L4.1, TP16.1, XT1.2 (+); also elsewhere on the board
Vchassis: F1.1, F2.1, R56.4, XT3.2 (+)

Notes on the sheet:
机械孔
PMOS关断电路
半桥与PMOS开关延迟电路
这个磁环电感在淘宝买，或者自己绕
这里的电容全部使用耐压50V或者以上的
主拓扑
底盘并联支路
辅助电源

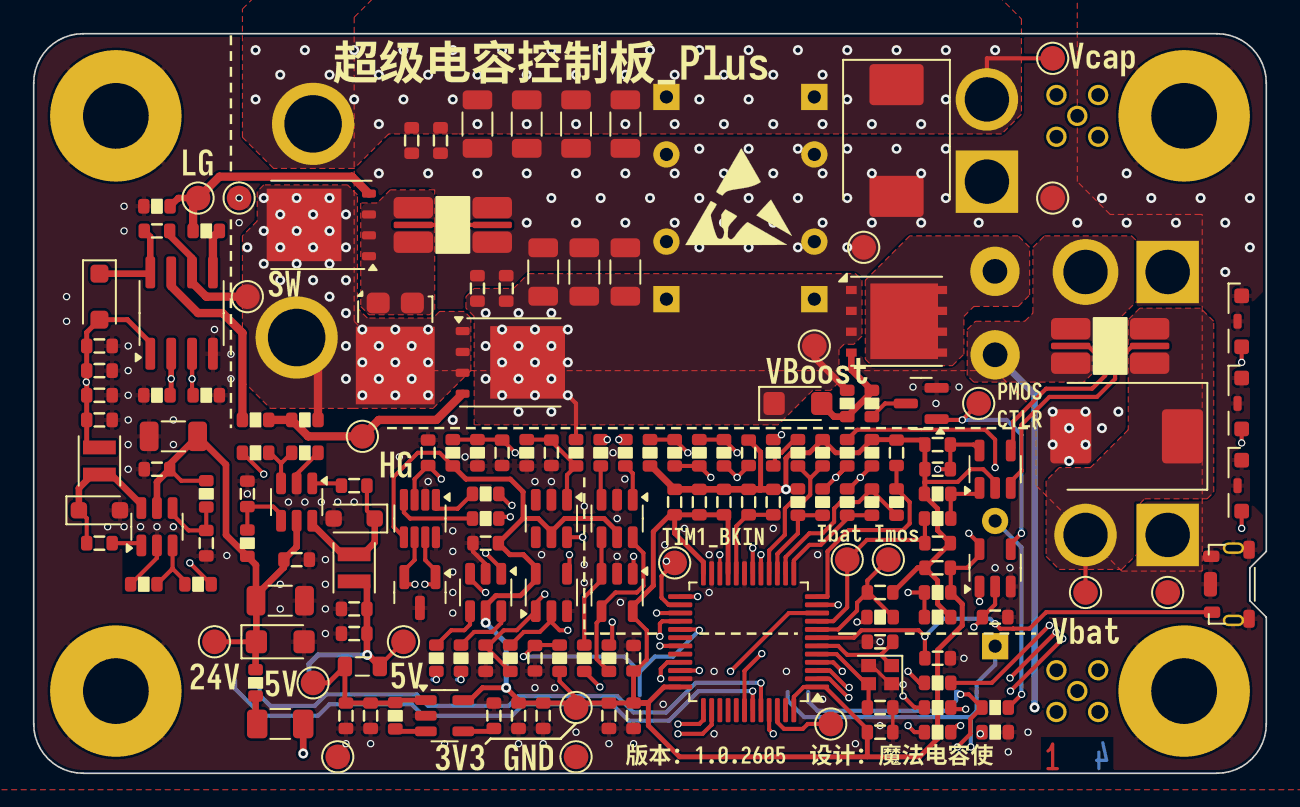
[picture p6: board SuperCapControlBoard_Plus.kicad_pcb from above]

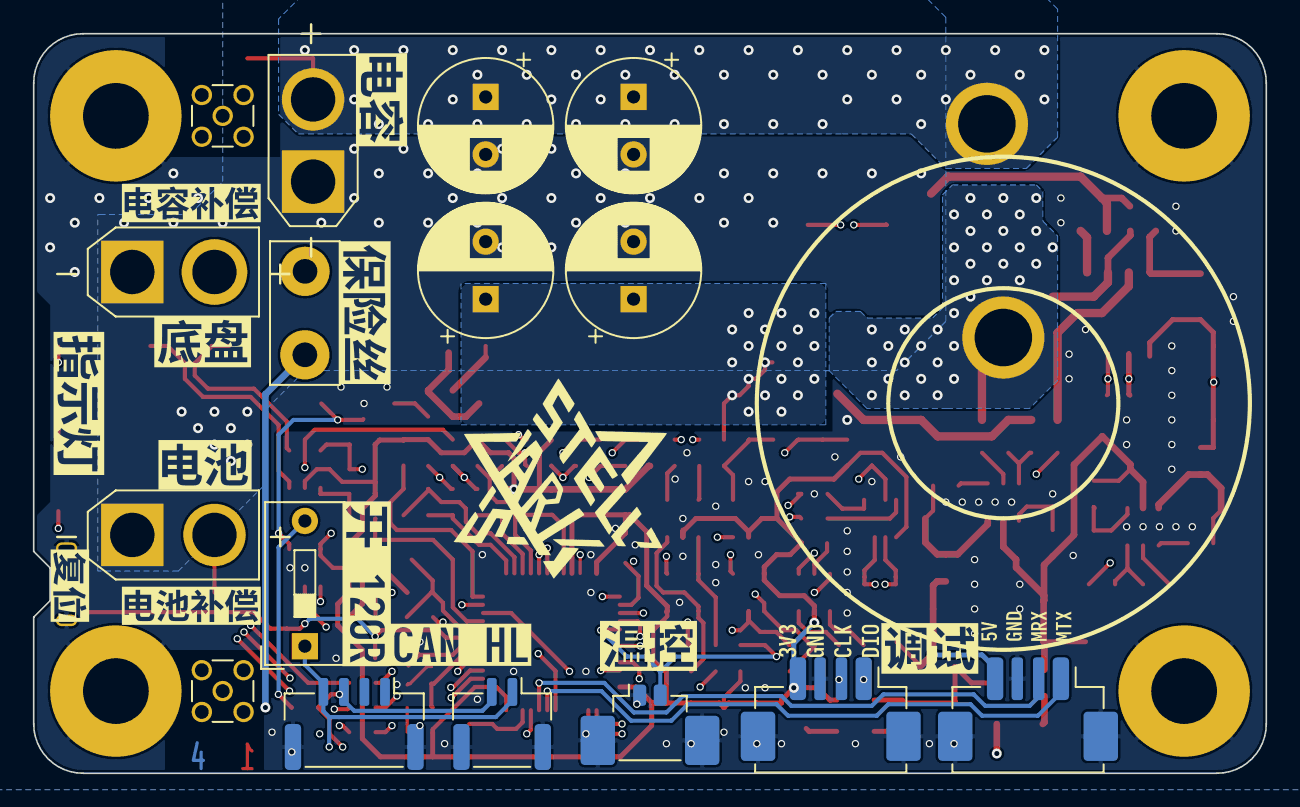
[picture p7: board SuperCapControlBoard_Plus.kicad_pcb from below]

Board: 4 copper layers, 75.0 x 45.0 mm, 190 parts (17 on the bottom side), 94 nets.

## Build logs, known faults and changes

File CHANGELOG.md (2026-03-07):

# 更新日志

## [1.0.2605] - 2026-01-19

### 新增

- SCH、PCB：添加PMOS_CTRL和TIM1_BKIN测试点

### 修复

- SCH：参考电压网络标签错误（实际0.82V，之前标的1.65V）
- PCB：将所有文本丝印转为图形，以免字体丢失产生乱码

## [1.0.2529] - 2025-07-20

### 新增

- PCB：添加压层顺序在铜层内
- PCB：添加LED和按键的3D

### 变更

- PCB：删除位号丝印（之前忘记删了）

## [1.0.2518] - 2025-05-04

### 变更

- SCH、PCB：栅极驱动由IR2181替换为LM5109
- SCH、PCB：将辅助电源的输入调整到检流电阻后，以将板子功耗记入（约0.2W）

### 修复

- PCB：LED指示灯封装错误
- PCB：MMCX-KWE接口干涉

## [1.0.2514] - 2025-04-06

### 首次发布

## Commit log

2026-03-06 建立仓库
    [POWER.kicad_sch, SuperCapControlBoard_Plus.kicad_pcb, SuperCapControlBoard_Plus.kicad_sch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]
2026-03-07 添加LICENSE
2026-03-07 添加GERBER文件，更正PCB版本丝印为2605
    [SuperCapControlBoard_Plus.kicad_pcb]
2026-03-29 ``` docs(README): 更新技术文档说明并修正描述错误
    - 将全差分放大器重要性说明加粗强调
    - 修正下管续流采样误差问题的描述，澄清软件限制措施
    - 调整保险丝熔断检测章节标题层级
    - 修正PMOS与PWM时序延迟保护章节标题层级
    - 优化电源远端电压补偿参考链接格式
    - 在STM32引脚说明中明确BOOM_IN引脚标识
    chore(kicad): 添加PCB用户注释并调整图层设置
    - 在PCB中添加关于LED安装方式的用户注释
    - 调整KiCad项目文件的活动图层设置
    ```
    [SuperCapControlBoard_Plus.kicad_pcb]
2026-09-25 docs(readme): 重构超级电容控制板 Plus 项目说明
    - 更新项目简介与 2025 赛季开源背景
    - 补充主要特性、硬件规格与工程结构
    - 增加固件仓库、物料打样、参考文献与特别鸣谢
    - 优化文档排版与配图展示
